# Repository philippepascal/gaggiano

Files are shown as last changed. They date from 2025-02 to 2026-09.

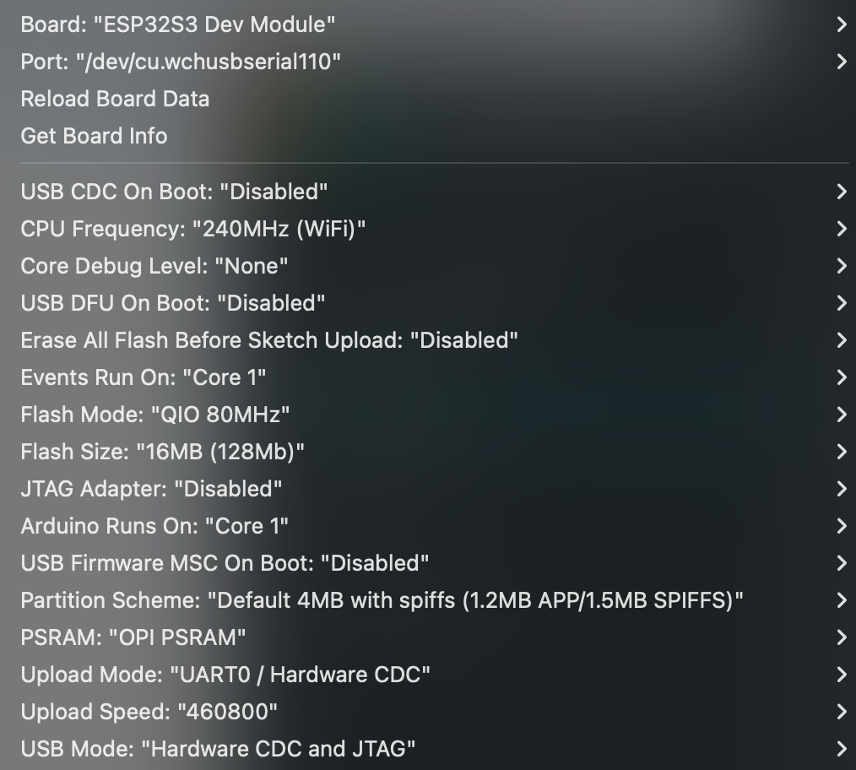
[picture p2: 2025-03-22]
docs/images/arduino-ide-esp32-settings-2025-03.png

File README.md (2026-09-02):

# Gaggiano

Firmware for a Gaggia espresso machine retrofit, inspired by
[Gaggiuino](https://github.com/Zer0-bit/gaggiuino) but written from scratch around two
boards:

| Board | Sketch | Role |
|---|---|---|
| STM32F411CEU6 "Black Pill" | `gaggiano-controller-v1/` | reads boiler temperature (MAX6675) and pressure (ADS1115), drives the boiler SSR, the pump (pulse-skip modulation) and the 3-way solenoid |
| Sunton ESP32-8048S043 (ESP32-S3, 4.3" 800x480 touch) | `gaggiano-v2/` | LVGL touch UI, brew profiles and logs on SD card, sends setpoints to the controller over UART |

The two talk over a 115200 baud serial link with a small text protocol with checksums,
a 1 s heartbeat from the screen and a 3 s safety timeout on the controller; see
`docs/PROTOCOL.md`. The protocol code is shared by both firmwares and tested on the
host (`libraries/GaggiaProtocol/`, `tests/`). Wiring follows the Gaggiuino "Lego build"
schematic in `docs/images/gaggiuino-lego-schematic-v3.9.png` with pin assignments as in
the sketches (`gaggiano-controller-v1/config.h`, `gaggiano-v2/config.h`).

## Building and flashing

Everything goes through the `./gg` script (arduino-cli underneath, no Arduino IDE):

```
./gg setup                 # once: pin the cores, write the local config
./gg build all
./gg flash screen          # esptool over the display's USB port
./gg flash controller      # DFU over USB with dfu-util, no buttons needed after the first flash
./gg monitor controller
./gg test                  # host-side tests of the protocol, profile format, sequencer
```

Both boards answer commands on their USB console (`tools/serial-cmd.py controller STATUS`,
`tools/serial-cmd.py screen STATUS`; `--help` lists them). `docs/BENCH-CHECKLIST.md` is
the manual verification run after a change.

- `docs/BUILD.md`: setup, commands, layout, troubleshooting.
- `docs/FLASH-STM32.md`: how the STM32 gets into DFU, the serial-triggered reboot,
  the button sequence, the ST-Link alternative.
- `sdcard/`: what goes on the display's SD card.
- `docs/2026-09-01-findings.md` and `docs/MIGRATION-PLAN.md`: state of the project and
  the record of the move away from the Arduino IDE.
- `docs/REFACTOR-PLAN.md`: the bug inventory and the refactoring record (protocol v2,
  memory fixes, watchdog, tests).

## Layout

```
gg, tools/            build/flash tooling
gaggiano-controller-v1/, gaggiano-v2/   the two sketches
libraries/            vendored Arduino libraries (with the project lv_conf.h)
sdcard/               SD card content for the display
vendor/               display board datasheets and schematics
gaggiacover/          3D models for the screen enclosure
archive/              first version of the display firmware
docs/                 documentation and images
```

## Known issues and ideas

From `notes.txt`, the working list, updated after the 2026-09 refactor:

- Communication stopping: the screen leaked heap on every status line and ran out
  within minutes; fixed (see `docs/REFACTOR-PLAN.md`, B1). To be confirmed in the machine.
- Pressure readout noisy on the screen: the reader now drains every pending line and
  shows the newest at 5 Hz; smoothing strategy still open.
- Boiler PID does not settle cleanly: zero readings from the MAX6675 used to pass the
  range check and reach the PID; fixed (B2). Re-check in the machine before retuning.
- Steam pressure declines over a long steam; needs a strategy to hold some pressure.
- Full controller logs on the SD card would help tuning; log format needs a header and
  a way to tie settings to a log (hash of the settings).
- Blooming: the pre-infusion fill time may not be consistent between the first and
  subsequent shots; a "stop pump when water detected" command is a candidate fix.

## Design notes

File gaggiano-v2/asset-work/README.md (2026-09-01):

Source images for the UI. Only `logoMainScreen.png` is currently compiled in (as
`../logoMainScreen.c`, generated with the LVGL image converter v8,
https://lvgl.io/tools/imageconverter, RGB565). The others are kept for future use.

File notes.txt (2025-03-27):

sometimes comms stop. no idea what is happening.
complete logs with additional settings or maybe hash of settings to compare with UI
nicer UI?
do I need to stop at detect pressure with special command? blooming fill time might not be consistent if first or subsequent shot

---------------Below is done:

current state:
coffee is decent, pressure control does something, though the readout on the screen is all over the place. need to figure out frequency of updates as controller sends more than screen receives
- let's add the use of Kalman filters to smooth out readings.
- increased greatly loop frequency to allow for many pressure readings.
temperature control seem iffy too. PID doesn't seem to find a way to stabilize at the right temp. often fall to bang bang range before bumping too high.
look into kalman filter

- it would be real nice to see full logs of controller: all messages, with included readings, and outputs over time. would require logging on the screen in the SD card. maybe need to create new log file at every start.
- logging would also probably require to not skip messages if several are logged in. multiple message reading and averaging for display might be good

channelling sometimes, already has a simple way to ease in pressure, not sure if it works great
- steam pressure declines a lot, and PID instability doesn't help. should look at how to maintain a bit of pressure when steaming
- cleaning cycle would be nice to have also, easily lifted from gaggiuino

brew cycle:
1. instanciate pump low until pressure changes (detect water)
    this can't be done in screen...need special function and message
2. if blooming:
2.a. run pump low just enough to add a bit of water
2.b. wait blooming time
3. increase pump smoothly till brew pressure reached
    also needs to be done in controller. but probably ok on all brew cycles
4. run pump on PID until timer done, or button pressed
5. display brew run time for reference to set timer

1.send special prime command: temp + pressure at which to stop pump but not before running a few seconds at desired pressure to add water
2.when pressure read reached desired, controller has already stopped, screen move to blooming
3.if blooming time >0 wait that amount of time
4.resume with simple brewing

- reset logs!!

timer on brew
 - start with display brew time
blooming!

 - add pump settings to advanced settings
 - persist steam settings
 - fix set temp on front panel when steaming
- no header on logs
 - fix sudden drop in pump output. combined with gradual increase, causes massive "holes" in pressure profile

 - fix last brew time random showings

sometimes comms stop. no idea what is happening.
complete logs with additional settings or maybe hash of settings to compare with UI

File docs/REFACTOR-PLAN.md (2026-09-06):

# Refactoring plan: fixes, structure and protocol (started 2026-09-01)

Branch `refactoring`, on top of `main` after the migration. Companion documents:
`docs/2026-09-01-findings.md` (project state), `docs/MIGRATION-PLAN.md` (tooling),
`docs/BUILD.md` and `docs/FLASH-STM32.md` (how to build and flash).

## Scope

In: bug fixes, memory safety, code structure, a robust screen/controller protocol,
host-side tests for the pure logic, bench verification of every step.
Out: new features, UI redesign, core or library upgrades (plan 6.3), anything that
changes what the machine does beyond the documented fixes below.

Rule for every step: it compiles with `./gg build all`, it is flashed with `./gg flash`,
and the bench checklist (R0.3) passes before the next step starts. One commit per
numbered step, message prefixed `refactor:`.

## How to resume after an interruption

1. `git checkout refactoring && git status && git log --oneline -15`.
2. Find the first unchecked box. Steps are ordered inside a phase; phases are ordered.
3. Steps marked **(bench)** need both boards on USB. Nothing here needs the boards in
   the machine until the final soak in R3.
4. Record surprises in the notes log at the end of this file.

## Decisions (answered 2026-09-01)

- D1. Link-loss behaviour on the controller: after N seconds without a valid command,
  pump off and valve closed for sure. Boiler: keep the last temperature setpoint
  (machine stays hot, proposed) or drop to 0? Proposed N = 3 s.
  **Decided: keep the boiler setpoint. N = 3 s.**
- D2. Protocol stays text with a checksum (proposed), not binary. **Decided: yes.**
- D3. Profile names capped at 24 characters (SD filename budget). Longer names are
  truncated on rename. **Default accepted.**
- D4. Enable the STM32 independent watchdog (resets the board if the loop hangs; a
  reset means pump off, valve closed, boiler PWM 0 until the screen re-sends). Proposed yes.
  **Decided: yes, try it.**
- D5. Host tests: plain C++ with a tiny assert helper and a Makefile, run by `./gg test`.
  No framework dependency. Proposed yes. **Default accepted.**
- D6. `double` to `float` on the controller where values only feed float APIs. The
  F411 has a single-precision FPU; doubles are emulated. Proposed: do it only in the
  new code paths (protocol, sensors); leave AutoPID's doubles alone. **Default accepted.**

## Bugs found by reading the code (fixed in the phases below)

| # | Where | What | Effect | Fixed in |
|---|---|---|---|---|
| B1 | both sides, `mySubString` (three copies) | `malloc` per field, never freed | screen leaks ~4 blocks per status line (5/s); controller leaks per command. Likely the "comms sometimes stop" symptom | R1.3 (controller), R2.4 (screen) |
| B2 | controller `readTemperature` | `newReading > 1 \|\| newReading < 200` always true | MAX6675 fault/zero readings pass into the PID | R1.2 |
| B3 | controller `loop` | `LOOP_PERIOD - (millis() - loopStart)` is unsigned; a loop over 10 ms yields a ~49-day `delay()` | firmware freezes with outputs held at their last value | R1.1 |
| B4 | controller `parseMessage` | unknown or truncated message falls through to `operating_mode = BREW` | mode switch on line noise, e.g. during steam | R1.3 |
| B5 | both sides | no checksum, no field-count check | a flipped digit changes a setpoint silently | R2 (checksum, field count) |
| B6 | controller | UART RX buffer 64 bytes, read every 200 ms; longest command 58 bytes | two commands within 200 ms truncate the second | R1.4, R2.4 (512 B on the screen) |
| B7 | screen | commands sent once, never refreshed; controller never times out | a lost "stop" keeps the pump running; a dead link freezes the machine state | R2 (heartbeat, timeout, echo check) |
| B8 | screen `readMessage` | `readStringUntil` blocks up to 50 ms in the UI loop; one line per pass | UI stutter, stale or skipped status lines | R2.4, R3.2 |
| B9 | screen `gaggia_config.cpp` | `malloc(30)` + `strcat` of profile names; `sprintf` of notes into 500 bytes; `new char[500]` never freed | stack/heap overflow with long names or notes; leak per profile load | R3.1 |
| B10 | screen `setupAndReadConfigFile` | reads `values[0..18]` without checking how many rows the CSV had | garbage settings from an old or truncated profile file | R3.1 (profile_format.cpp, tested) |
| B11 | screen `state.notes`, `state.profile_name` | `char*` pointing at leaked heap or string literals | undefined lifetime, leak per load | R3.1 |
| B12 | controller `parseMessage` | 500-byte line buffer on the stack plus `String` from `readStringUntil` | heap churn, stack pressure; no bound on line length | R1.3 |

## Target layout (end state)

```
libraries/GaggiaProtocol/          shared by both sketches and the host tests
  library.properties
  src/gaggia_protocol.h            message types, field lists, limits, version
  src/gaggia_protocol.cpp          encode / decode / checksum, no heap, no Arduino deps
  src/line_reader.h                non-blocking line assembler over any byte source
gaggiano-controller-v1/
  gaggiano-controller-v1.ino       setup() / loop() only
  config.h                         pins, periods, limits
  sensors.{h,cpp}                  MAX6675 + ADS1115 + Kalman
  outputs.{h,cpp}                  boiler PWM, pump (PSM), valve, allOutputsOff()
  control.{h,cpp}                  mode logic (brew / steam / clean), PID glue
  link.{h,cpp}                     screen UART: STAT out, CMD/TUNE in, link timeout
  console.{h,cpp}                  USB serial: VERSION, DFU, STATUS, LOG
  dfu_jump.{h,cpp}                 unchanged
  PSM.{h,cpp}                      unchanged
  build_opt.h                      -DSERIAL_RX_BUFFER_SIZE=256
gaggiano-v2/
  gaggiano-v2.ino                  setup() / loop() only
  display_glue.{h,cpp}             Arduino_GFX panel, LVGL flush, touch (unchanged behaviour)
  sequencer.{h,cpp}                brew/bloom/auto phase machine, pure logic, time injected
  link.{h,cpp}                     controller UART: CMD/TUNE out with heartbeat, STAT in
  storage.{h,cpp}                  SD: profiles, settings, logs (was gaggia_config.cpp)
  gaggia_state.h                   fixed-size strings instead of char*
  lv_buildUI.{h,c}                 UI only; no parsing helpers
tests/
  Makefile                         host build with the system compiler
  test_protocol.cpp, test_sequencer.cpp, test_line_reader.cpp
docs/PROTOCOL.md                   the wire format, one page
```

---

## Phase R0: baseline and safety net (no bench)

- [x] R0.1 Starting commit: `main` at 2f58621 (Migration #1). Save the current
      binaries as `build-baseline/` locally (git-ignored) for size comparison.
- [x] R0.2 `tests/` with a Makefile that compiles listed `.cpp` files with the host
      `c++`, plus `./gg test`. A first trivial test proves the harness. CI runs it.
- [x] R0.3 `docs/BENCH-CHECKLIST.md`: the manual verification run after every flash.
      Draft:
      1. `./gg detect` shows both boards. `./gg monitor controller`, `VERSION` answers.
      2. Screen boots to the main tab; temperature and pressure update about 5 times/s.
      3. Heat on: controller log shows the setpoint; boiler output rises. Heat off.
      4. Brew on for 5 s: valve opens, pump output non-zero, brew timer counts. Brew off:
         valve closes, pump 0.
      5. Steam on/off, clean on/off: mode echoed by the controller.
      6. Settings tab: change a value, Set, reboot the screen, value persists.
      7. Profile tab: duplicate, rename, select, delete. Names survive a reboot.
      8. Leave both boards running 10 minutes; free heap (screen) and loop counter
         (controller) still reported and stable.
      Items 1-2 after every flash; the full list at each checkpoint.
- [x] R0.4 (both verified on bench) Controller console additions needed for the checklist: `STATUS` (mode,
      setpoints, outputs, loop counter, max loop time, link state) and `LOG ON|OFF`
      (silence the per-message debug spam). Screen: print free heap every 10 s to USB.

**Checkpoint R0:** `./gg test` passes, checklist items 1-2 pass with the current
firmware (PASSED 2026-09-01 for the controller; `STATUS` reports maxLoopMs=6 at rest), baseline sizes recorded: controller 68,080 bytes, screen 678,224 bytes.

---

## Phase R1: controller fixes and structure (no protocol change) **(bench)**

The wire format stays exactly as today so the screen keeps working unmodified.

- [x] R1.1 Fix B3: compute elapsed time, `delay` only when elapsed is below the period;
      track the maximum loop time for `STATUS`.
- [x] R1.2 Fix B2 (`&&`), and treat a MAX6675 open-thermocouple reading (NaN or 0) as a
      fault: keep the last good value, count faults, expose in `STATUS`.
- [x] R1.3 Fix B4/B12/B1 on the controller: replace `parseMessage` with a non-blocking
      line assembler (fixed 128-byte buffer, characters pulled every loop pass) and an
      in-place `strtod` field parser. Unknown type or wrong field count: ignore, count.
      Delete `mySubString`, `myIndexOF`, the dead `updatePump`.
- [x] R1.4 Fix B6: `build_opt.h` with `-DSERIAL_RX_BUFFER_SIZE=256`; verify the flag is
      honoured in the verbose build output.
- [x] R1.5 Split the sketch into the files listed above. Pure move, no logic change;
      confirm the `.bin` size is within a few hundred bytes of R1.4.
- [x] R1.6 D4: enable the independent watchdog (STM32duino `IWatchdog`, 4 s), reloaded
      once per loop. Verify: `HANG` console command spins forever; the board resets
      within 4 s and comes back with outputs off.
- [x] R1.7 SKIPPED: the new parser writes into the double setpoints AutoPID points at; converting nothing else buys anything measurable (loop max 6 ms). Revisit if the loop budget gets tight.

**Checkpoint R1:** full bench checklist with the unmodified screen firmware. Ten
minutes of heat + a 30 s brew with the console showing loop max time under 10 ms.
PASSED 2026-09-01. Console items: VERSION, STATUS, LOG, RX injection of valid and
invalid lines, HANG -> watchdog reset in 4 s with wdReset=1, DFU flash with the watchdog
armed. Screen-driven run captured on the controller console with LOG ON: heat on/off
(boiler 100% then 0), brew on/off (valve 1, pump ramp 0.8 -> 126.85 at 0.4/step, then 0),
steam on/off (pump 5.08 = 4% of 127, valve stays 0, boiler 100), clean on/off (valve 1,
pump 255), three advanced-settings sends from Set / duplicate / delete. STATUS after:
rx=12 rxRejected=0 rxOverflows=0 maxLoopMs=6 (with logging on), 575 status lines with
no counter gaps. Not done: the 10-minute heat with water (bench only, no machine).

---

## Phase R2: shared protocol v2 **(bench)**

Both sides change together; both boards are flashed together.

- [x] R2.1 `docs/PROTOCOL.md`. Proposed format (D2), NMEA-style:

      ```
      $TYPE,field,field,...*HH\n
      ```
      `HH` is the XOR of every byte between `$` and `*`, two upper-case hex digits.
      Fields are decimal with at most 2 decimals; a receiver rejects a line whose type
      is unknown, whose checksum fails, or whose field count is wrong. Line length is
      capped at 120 bytes.

      | Type | Direction | Fields | When |
      |---|---|---|---|
      | `HELLO` | both | protocol version, firmware version string | on boot, and as reply to `HELLO` |
      | `STAT` | controller to screen | mode, temp, pressure, valve, boilerOut, pumpOut, tempSet, pressSet, pumpPct, linkOk, faults, counter | every 200 ms |
      | `CMD` | screen to controller | mode (0 off, 1 brew, 2 steam, 3 clean), tempSet, pressSet, pumpPct | on change and every 1 s (heartbeat) |
      | `TUNE` | screen to controller | bbRange, pidCycle, kp, ki, kd, pumpStepUp, pumpKp, pumpKi, pumpKd | on change, and after every controller `HELLO` |

      Controller rules: no valid `CMD` for N s (D1) sets mode 0, pump 0, valve closed,
      `linkOk=0` in `STAT`. Screen rules: if `STAT` echoes a mode or setpoint different
      from what it last sent for more than 1 s, re-send `CMD`. `TUNE` is re-sent whenever
      the controller says `HELLO` (it rebooted). The SD log keeps the raw `STAT` lines;
      the header row changes accordingly.
- [x] R2.2 `libraries/GaggiaProtocol`: encoder, decoder, checksum, `line_reader.h`.
      No heap, no `String`, no Arduino types (a `putc`-style callback for output). Host
      tests: round trip of every message, checksum failure, truncated line, garbage
      before `$`, field count mismatch, oversize line, two lines in one read.
- [x] R2.3 Controller `link.cpp` on the library: `STAT` every 200 ms, `HELLO` at boot,
      `CMD`/`TUNE` handling, link timeout. Mode changes only from a valid `CMD`.
- [x] R2.4 Screen `link.cpp` on the library: heartbeat, echo check, `TUNE` after `HELLO`,
      RX buffer 512 (`setRxBufferSize` before `begin`), all pending lines drained each
      pass, newest `STAT` wins.
- [x] R2.5 (see checkpoint notes) Flash both. Bench: full checklist, then pull the UART wire mid-brew: pump
      stops within N s, `STAT` shows `linkOk=0` on the console; reconnect: screen
      re-sends within 1 s, brew resumes only if still selected on the screen. Reset the
      controller with NRST while heating: screen re-sends `TUNE` and `CMD` unprompted.

**Checkpoint R2:** the above, plus `./gg test` green.
PASSED 2026-09-01 with one item deferred. Host tests: 244 checks green. Bench, screen
console: HELLO exchange at boot, TUNE sent, one rejected partial line at startup as
designed, CMD heartbeat at 1 Hz, every button press one CMD change, zero rejects and
zero re-sends over a 10-minute run, heap flat except during profile/settings saves
(B9, next). Controller reboot with NRST while heating: screen received HELLO, re-sent
TUNE and the heat CMD unprompted. Controller console (by injection): CMD accepted,
mode 0 and linkOk=0 three seconds later. Deferred: the UART wire pull. The screen's
USB bridge dropped at the moment the wire was pulled (twice during hardware handling
in this session, looks like a ground glitch), hiding the re-send message; to be
observed from the controller console at Checkpoint R3 instead.

---

## Phase R3: screen fixes and structure **(bench)**

- [x] R3.1 (bench 2026-09-01: heap flat at 113,112 through two saves, duplicate, three profile switches, delete, notes save; 14 min idle flat) Fix B9/B10/B11: `gaggia_state.h` gets `char profile_name[32]` and
      `char notes[128]`; all filename building through one `snprintf` helper with the D3
      cap; the CSV loader checks the row count and falls back to defaults per missing
      field; every `malloc`/`new` in `storage.cpp` and `lv_buildUI.c` removed or paired
      with a free (target: zero heap allocation after boot outside LVGL and the SD driver).
- [x] R3.2 Fix B8 leftovers: the `i < 20` loop hack becomes time based (`STAT` consumption
      and UI refresh at 5 Hz, `lv_timer_handler` every 5 ms); no blocking reads remain.
- [x] R3.3 `sequencer.cpp`: the bloom/auto/brew phase machine extracted from
      `sendCommand` into a pure function of (state, now) that returns the desired `CMD`.
      Host tests for the phase transitions and timers.
- [x] R3.4 `display_glue.cpp`: panel, LVGL driver, touch and splash moved out of the
      `.ino` unchanged.
- [x] R3.5 Logging: `logController` keeps the file open between lines and flushes once a
      second; `deleteLogsFile` writes the new header. Free-heap line to USB every 10 s.
- [x] R3.6 PARTIAL: parsing helpers removed and fixed-size strings in use (done in R3.1). DEFERRED: folding the ten settings-field blocks (cosmetic, risk of pixel drift) and the delete-selects-first-profile quirk. `lv_buildUI.c`: remove the parsing helpers, use the fixed-size strings, and
      fold the ten copy-pasted settings-field blocks into one helper. Pixel-identical
      screens; (no screenshot of the old UI exists; the file once named so was an IDE capture).
- [x] R3.7 Debug output behind one log-level switch on both sides.

**Checkpoint R3:** full bench checklist, then a 1-hour soak with both boards on USB:
free heap flat on the screen, loop max time stable on the controller, no missed
`STAT` lines in the SD log (counter field contiguous).
PASSED 2026-09-01 (screen on USB, controller powered through the link connector).
Checklist: heat, brew, steam, clean, prime to completion, auto to completion, settings
save, profile duplicate/select/delete: one command change per press, zero rejects, zero
re-sends. Two pre-existing UI bugs found and fixed on the way: the tab bar stayed
disabled after prime/auto ended on their own; the action timer restarted at each phase
(now continuous, and the prime button shows fill+wait). Display precision reduced to the
degree / 0.1 bar / second. Soak 17:16 to 18:16: 360 HEAP lines all at 112,592 bytes;
21,505 status lines received in 4,521 s (4.76/s, matching the 200 ms send period with
loop jitter) with the reject counter unchanged; no port drops. Not done: SD log
continuity (SDLOG left off). UART wire pull done afterwards with the controller on USB:
`link timeout: mode off` 3 s after the unplug, boiler setpoint kept (D1). Pulling the
four-pin link connector also cuts the screen's power in this bench setup, so the replug
is a screen reboot: HELLO exchange, the screen's initial off command applied, heartbeat
resumed. A data-only wire pull is not possible with this connector; the recovery path
via heartbeat and HELLO is demonstrated by the reboot.

---

## Phase R4: wrap-up

- [x] R4.1 README: protocol summary and link to `docs/PROTOCOL.md`; findings doc gets a
      "resolved" column for B1-B12; this plan's boxes ticked.
- [ ] R4.2 One test in the machine: heat, one shot, one steam. Compare against how it
      felt before the refactor; no tuning changes are expected.
- [ ] R4.3 PR `refactoring` to `main`.

## Deferred (not this branch)

- Screen boot blocks for the 5 s splash before the loop and the heartbeat start, so the
  controller sees a 3 s link timeout on every screen reboot (harmless: mode is off
  anyway). A non-blocking splash would remove it.

- Core and library upgrades (migration plan 6.3), 16 MB partition table.
- Items from `notes.txt`: pressure readout smoothing strategy, PID retune, steam
  pressure hold, "stop pump when water detected" prime command, settings hash in logs.
- `double` to `float` inside AutoPID and the PID tuning that would need re-validation.

## Notes log

- 2026-09-01 sensor faults: with the boards idle on the bench, the controller counted
  122 rejected MAX6675 readings in about an hour (one every ~30 s). Before R1.2 these
  zero readings went straight into the boiler PID (the range check was always true),
  which fits the old "PID never settles, drops into bang-bang then overshoots" note.
  Worth re-checking the PID behaviour in the machine before any retuning.

- 2026-09-01 R3.1 bench: after deleting a profile the UI selects the first profile in
  the list (`tigerwalk`), not the one that was selected before the duplicate. Pre-existing
  behaviour in `delete_btn_clicked`; candidate for R3.6.

- 2026-09-01 screen baseline: right after boot the screen reports
  `HEAP free=114128 minfree=105320 psramfree=7590603`.
- 2026-09-01 B1 measured live: with status lines flowing the screen's internal heap
  fell about 4.1 KB per 10 s and reached `free=0` within a few minutes of boot. After
  that, allocations spill into PSRAM at the same ~420 B/s and the UI keeps running, but
  anything needing internal RAM (UART and SD drivers included) is at risk. This is the
  most likely mechanism behind "comms sometimes stop". Fixed in R3.1; the after
  measurement must show a flat HEAP line for 10 minutes.
- 2026-09-01 bench logistics: only one working data cable, so the two boards are put on
  USB one at a time. Either board powers the other over the shared 5 V rail (the display
  board's power connector passes current both ways through Q1), so the UART link stays
  up regardless of which one is on the Mac.

- 2026-09-01 R1: `STATUS` reports maxLoopMs=6 at rest with debug logging off. That is
  close to the 10 ms loop period; with `LOG ON` the USB prints likely pushed some
  iterations past 10 ms, which is exactly the B3 trigger. B3 is fixed, but the
  MAX6675 bit-banged read (every 250 ms) is the main cost and worth a look if the
  budget matters later.
- 2026-09-01 R1.6: the independent watchdog stops on the software reset used for the
  DFU jump (verified: buttonless flash works with it armed), and `wdReset` is reported
  by `STATUS` after a watchdog reset.

- 2026-09-01: plan written from a full read of both sketches, `gaggia_config.cpp`,
  `PSM.cpp` and the UI event handlers. The three `mySubString` copies (controller,
  `gaggia_utils.cpp`, `lv_buildUI.c`) all leak. B3 (unsigned delay underflow) was
  found while planning and is possibly the more direct cause of "comms stop".

- 2026-09-04: field failure, boiler warm, a clean cycle done. 11 s after the clean
  stopped the ADS1115 stopped answering on I2C. Each pressure read then blocked for the
  core's 100 ms I2C timeout (loop counter 10 per second instead of 100) and the library
  returned raw 0, shown as -1.50 bar. The slow loop exposed an unsigned underflow in
  `checkLinkTimeout`: `now` is the loop start while `last_cmd_time` is stamped after the
  read, so every heartbeat was applied then timed out in the same pass (mode off,
  `linkOk=0`, boiler setpoint kept). The screen showed nothing. Fixed: signed difference
  in `checkLinkTimeout`; failed pressure reads keep the last value, count as faults, are
  retried every 250 ms with an I2C bus recovery every 8 failures, and `pressureStale`
  keeps the pump off; `I2C_TIMEOUT_TICK` lowered to 20 ms in `build_opt.h`; the screen
  header warns `CONTROLLER SILENT` / `CONTROLLER IGNORES COMMANDS`. Why the bus hung is
  not known from the log (EMI from the SSR or pump relay on the I2C wires is the
  suspect; check the pull-ups and the routing).
- 2026-09-04 protocol v3: `STAT` carries `pressStale`, `i2cRecoveries` and
  `maxLoopMs`, logged as three more CSV columns, and the screen writes its own event
  rows (`<time>,#,<text>`) into the same session log: commands sent and why, tuning
  sent, controller hello, rejected lines, silent/answering, link warnings, pressure
  sensor stale/live, screen boot. The two firmwares must be flashed together (a v2
  `STAT` is rejected on field count by a v3 screen and the other way round).
- 2026-09-05: pump dead on some boots, fine on others, nothing touched on the
  machine. The `PSM` object (pulse-skip pump driver) is created with `new` and none
  of its counters had an initialiser; the heap is not zeroed at boot, so
  `_stopAfter`/`_counter` came up with whatever the SRAM held. With the wrong
  values the zero-cross ISR takes the "stopAfter reached" branch on the first
  half-cycle and `_skip` stays true for good. The 2026-09-04 build moved the heap
  (new globals) onto cells that happen to power up that way, which is why it
  appeared right after a firmware change. All members now have initialisers;
  `STATUS` prints `zc=` (zero crossings seen) so a missing dimmer signal is
  visible on the bench (checklist row 17).
- 2026-09-05 steam assist, protocol v4: steaming used to run the pump at a fixed
  percent whenever the pressure was under the max, which either did nothing (the
  pump's own pulses raise the line pressure and trip the cut) or overfilled the boiler
  (a 1.4 kW element vaporises about half a gram per second; the pump at 20% delivers
  more, and the excess comes out of the wand as water). Now `steam_assist.cpp` fires
  fixed shots (`steam_shot_s` of pump at the steam pump percent) at least
  `steam_gap_s` apart, only while the pressure is under the max (wand open) and the
  boiler is within 2 degrees of its setpoint (the element has spare heat to flash the
  water). Both timings are per profile, edited in the STEAM group of the settings, and
  travel to the controller in `TUNE` (11 fields). Host test: `tests/test_steam_assist.cpp`.
- 2026-09-05 evening, protocol v5, from the first steam assist log: with the wand open
  the boiler slid from 135 to 127 in 15 s while the heater sat at 20 to 60 percent, the
  10 degree bang-bang band and Kp 5 being too soft for the steam draw; the assist then
  waited at its 2 degree gate. Now steaming with the wand open narrows only the "flat
  out below" side of the bang-bang to `STEAM_OPEN_BB_RANGE` (3 degrees), the PID and the
  off side are unchanged and the wand closed restores the normal band. The gate is an
  absolute `steam_min_temp` per profile ("Assist min °C", 12th `TUNE` field), and the
  AUTO settings group folded into BREW as "Auto brew s" to make room for it.
- 2026-09-06 heater control, protocol v6: the vendored AutoPID library computed its
  derivative divided by the step twice (a million times too small, Kd never acted),
  had no anti-windup (the clamp was commented out) and took the derivative on the
  error. Replaced by `boiler_pid.cpp`, plain C++ with host tests: same bang-bang band
  and P/I arithmetic at today's gains, derivative on the measurement in degrees per
  second, integral clamped to the output range, a step after bang-bang starts from the
  current reading. The morning log also showed a brew pulling the boiler 3 to 4
  degrees under for 25 s with the heater at 28 percent, which is what 1.2 ml/s of
  reservoir water takes: `brewBoostPercent` adds that estimate to the PID output while
  the pump runs in brew mode (pump fraction x `pump_flow_ml_s` x 4.186 x rise / 1400 W,
  cap 40). `pump_flow_ml_s` replaces the unused advanced setting ("Flow ml/s at 100%",
  default 9, 13th `TUNE` field). The AutoPID directory can go.
- 2026-09-06 screen: a log download over WiFi used `streamFile`, which blocks the loop
  for the whole transfer (seconds for a long session): the panel froze and, past 3 s,
  the controller would have timed the link out and stopped a brew. `sendCsvFile` now
  sends 2 KB chunks and services the link and LVGL between them.

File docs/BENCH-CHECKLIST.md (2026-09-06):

# Bench checklist

Run items 1 and 2 after every flash. Run the whole list at each checkpoint of
`docs/REFACTOR-PLAN.md`. "Bench" means both boards on USB and wired to each other over
UART; nothing needs to be in the machine.

Console commands (`tools/serial-cmd.py controller <command>` or `... screen <command>`;
`tools/serial-cmd.py --list` shows ports). Controller: `VERSION`, `STATUS`, `LOG ON|OFF`,
`RX <protocol line>`, `HANG`, `DFU`. Screen: `VERSION`, `STATUS`, `LOG ON|OFF`, `SDLOG ON|OFF`.
With one data cable, put one board on USB at a time; either board powers the other
through the link connector.

| # | Step | Expect |
|---|---|---|
| 1 | `./gg detect` | both boards listed with a port |
| 2 | `VERSION` on the controller | the version string |
| 3 | `STATUS` on the controller | one line with mode, setpoints, readings, outputs, loop counter and max loop time (under 10 ms at rest) |
| 4 | Screen boots | main tab; temperature and pressure labels refresh about 5 times a second |
| 5 | Heat on from the screen | `STATUS` shows the temperature setpoint; boiler output above 0. Heat off: setpoint 0 |
| 6 | Brew on for 5 s | valve 1, pump output above 0, brew timer counting on screen. Brew off: valve 0, pump 0 |
| 7 | Steam on, then off; Clean on, then off | mode echoed in `STATUS` each time |
| 8 | Settings tab: change a value, Set, reboot the screen | value persists |
| 9 | Profile tab: duplicate, rename, select, delete | names correct after a screen reboot |
| 10 | Both boards running 10 minutes | screen prints `HEAP` lines every 10 s with a flat free value; controller loop counter still increasing; `STATUS` max loop time unchanged |
| 11 | Reboot the controller with NRST while the screen is heating | screen console shows `controller hello`, then `TUNE` and the heat `CMD` re-sent |
| 12 | Unplug the UART wire during a brew, wait 5 s, replug | controller console (`LOG ON`): `link timeout: mode off` within 3 s; on replug the next heartbeat restores brew within 1 s |
| 13 | Pull the pressure sensor's I2C wire (SDA or SCL) while heating | `STATUS`: `pressStale=1`, `pressFaults` counting, `i2cRecoveries` counting about every 2 s, `press` frozen at its last value, `linkOk=1`, loop counter still about 100 per second; screen keeps its buttons lit and shows no warning |
| 14 | Replug the I2C wire | within about 2 s `pressStale=0`, `press` live again, counters stop |
| 15 | Clean on with the I2C wire pulled | `STATUS`: mode 3, valve 1, `pumpOut=0.0` (the pump never runs on a stale pressure) |
| 16 | Unplug the UART wire while the screen heats | screen header shows `CONTROLLER SILENT` within 2 s; replug clears it |
| 17 | Power-cycle the machine 5 times (mains off, not just reset) and start a clean on each boot | pressure rises on every boot; `STATUS`: `zc=` climbing by about 100 per second whenever the mains is on |
| 18 | Steam with the wand closed, boiler at its setpoint | `STATUS`: `pumpOut=0.0` throughout (pressure above the max, no shot) |
| 19 | Open the wand while steaming at the setpoint | log: `pump` shows short bursts about `steam_gap_s` apart, none while `temp` is under `steam_min_temp`; `heater` 100 as soon as `temp` is 3 degrees under the setpoint; no water from the wand |
| 20 | Brew at the setpoint with a puck | log: `heater` jumps by about 20 percent the moment `pump` starts and drops back when it stops; `temp` stays within 1.5 degrees of `tempSet` through the shot |

Record anything unexpected in the plan's notes log.

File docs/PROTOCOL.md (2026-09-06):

# Screen / controller protocol, version 6

UART, 115200 8N1, 3.3 V. Controller USART2 (PA2 TX, PA3 RX); screen UART2 (GPIO17 TX,
GPIO18 RX). Text lines, one message per line, implemented once in
`libraries/GaggiaProtocol/` and used by both firmwares and by the host tests.

## Line format

```
$TYPE,field,field,...*HH\n
```

- `$` starts a message; anything before it on the line is ignored (boot noise).
- `TYPE` is one of the words below. Fields are separated by `,`.
- `*HH` is the checksum: XOR of every byte between `$` and `*` (both excluded), as two
  upper-case hex digits. A receiver drops a line whose checksum does not match.
- Numbers are decimal. Floats carry two decimals. Integers have no decimal point.
- A line is at most 120 bytes including `\n`. Longer lines are dropped whole.
- A receiver also drops a line whose type is unknown or whose field count is wrong.
  A dropped line never changes any state; it is only counted.

## Messages

| Type | Direction | Fields | When |
|---|---|---|---|
| `HELLO` | both | `version` (int), `firmware` (string, no commas, max 31 chars) | at boot. The controller also answers a `HELLO` with its own. |
| `STAT` | controller to screen | `mode` `temp` `pressure` `valve` `boilerOut` `pumpOut` `tempSet` `pressSet` `pumpPct` `linkOk` `faults` `counter` `pressStale` `i2cRecoveries` `maxLoopMs` | every 200 ms |
| `CMD` | screen to controller | `mode` `tempSet` `pressSet` `pumpPct` | on change, and every 1000 ms as a heartbeat |
| `TUNE` | screen to controller | `bbRange` `pidCycle` `kp` `ki` `kd` `pumpStepUp` `pumpKp` `pumpKi` `pumpKd` `steamShotS` `steamGapS` `steamMinTemp` `pumpFlow` | on change, and after every controller `HELLO` |

Field meanings:

- `mode`: 0 off (pump off, valve closed, boiler follows `tempSet`), 1 brew (pressure
  control to `pressSet`, valve open while `pressSet` > 0), 2 steam (valve closed, steam
  assist: shots of pump at `pumpPct` for `steamShotS`, at least `steamGapS` apart, only
  while the pressure is below `pressSet`, which means the wand is open, and the boiler is
  at `steamMinTemp` or more; `pumpPct` 0 or `steamShotS` 0 disables. With the wand open
  the heater is also flat out below `tempSet` minus 3 degrees instead of the normal
  bang-bang band), 3 clean (pump full on below `pressSet`, valve open).
- `temp` in degrees C, `pressure` in bar, `valve` 0/1, `boilerOut` 0..100 percent,
  `pumpOut` 0..127 (pulse-skip units), `tempSet` degrees C, `pressSet` bar, `pumpPct`
  percent.
- `steamShotS`, `steamGapS` (v4), `steamMinTemp` (v5) in `TUNE`: steam assist timings in
  seconds and minimum boiler temperature in degrees C, from the profile's steam settings;
  the other `TUNE` fields come from the advanced settings.
- `pumpFlow` (v6, `TUNE`): the pump's flow at full range at brew pressure, ml/s, from the
  advanced settings. While brewing the controller adds a heater feed-forward for the
  incoming water (pump level times this flow times the rise from 20 C to `tempSet`,
  capped at 40 percent) on top of the PID; 0 disables it.
- `linkOk`: 1 while the controller has received a valid `CMD` within the last 3 s.
- `faults`: count of rejected sensor readings since boot (temperature readings out of
  range plus pressure reads that failed on I2C; the controller console `STATUS` splits
  them).
- `counter`: the controller's loop counter (10 ms per count); gaps mean lost lines. A
  counter that climbs slower than 100 per second means the loop is stalling.
- `pressStale` (v3): 1 while the controller has had no valid pressure reading for
  500 ms; the pump is held off in every mode until a reading comes back.
- `i2cRecoveries` (v3): how many times the controller has clocked the I2C bus free
  and re-initialised the pressure ADC since boot.
- `maxLoopMs` (v3): the longest loop pass since the previous `STAT`, in ms. Normally
  under 10.

## Rules

- Controller: if no valid `CMD` arrives for 3 s, it sets mode 0 (pump off, valve closed),
  keeps `tempSet` (the boiler stays hot), and reports `linkOk=0`. The next valid `CMD`
  restores normal operation.
- Screen: it sends the current `CMD` immediately when it changes and at least every
  1000 ms. If two consecutive `STAT` lines echo a mode or setpoint different from the
  last `CMD` sent, it re-sends the `CMD`.
- Screen: it sends `TUNE` when the values change and whenever it receives a `HELLO`
  from the controller (the controller rebooted and has default tuning).
- The screen's SD log stores the `STAT` fields and the screen's own events, see below.

## SD log

One CSV per screen boot under `/gaggia/logs`, downloadable from the web page. The
header row is:

```
time,mode,temp,pressure,valve,heater,pump,tempSet,pressSet,pumpPct,linkOk,faults,counter,pressStale,i2cRecoveries,maxLoopMs
```

- `STAT` rows: one per `STAT` while the controller runs something, one per second
  otherwise. `heater` is `boilerOut`; `pump` is `pumpOut` scaled to percent. `time` is
  `-` until the clock is set.
- Event rows: `<time>,#,<text>`. Written by the screen when a `CMD` is sent for a
  reason other than the heartbeat (`cmd change ...`, `cmd mismatch ...`, `cmd hello
  ...`), when `TUNE` is sent, when a controller `HELLO` arrives (a reboot), when
  lines are rejected (at most one row per second), when the controller goes silent or
  answers again, when it reports the link down while heartbeats are being sent, when
  the pressure reading goes stale or comes back, and at screen boot. The text has no
  commas; readers skip rows whose second field is `#`.

## Example

```
$CMD,1,93.00,9.00,0.00*56
$STAT,1,92.85,8.97,1,34.0,88.40,93.00,9.00,0.00,1,0,123456,0,0,6*..
```

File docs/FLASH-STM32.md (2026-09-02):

# Flashing the STM32 controller

The controller is an STM32F411CEU6 "Black Pill". It is programmed over USB using the
chip's ROM bootloader (DFU). The bootloader lives in ROM, so no firmware bug can brick
the board: the button sequence below always works.

## Three USB identities

| State | VID:PID | What macOS shows | How to see it |
|---|---|---|---|
| Running our firmware | 0483:5740 | `/dev/cu.usbmodem<serial>` | `./gg detect`, `ls /dev/cu.*` |
| DFU bootloader | 0483:df11 | **nothing under /dev** | `./gg detect`, `dfu-util -l` |
| ST-Link probe (optional) | 0483:3748 or 0483:374b | nothing under /dev | `st-info --probe` |

The DFU bootloader is a plain USB device, not a serial port. This is why the Arduino IDE
port menu looked empty even when the board was correctly in DFU mode.

## Normal flash

```
./gg flash controller
```

What happens:

1. The sketch is built into `build/controller/`.
2. If the board is already in DFU mode, go to step 5.
3. If the board is running firmware that understands the `DFU` serial command (see
   below), `gg` sends it and waits up to 5 s for the bootloader to appear.
4. Otherwise it prints the button sequence and polls for the bootloader for 60 s
   (`--timeout` to change).
5. It downloads the binary with `dfu-util` (Homebrew, open source; ST's
   STM32CubeProgrammer is not needed, `--via cubeprog` uses it if installed), retrying
   up to 3 times, then waits for the firmware's serial port to come back.

## The button sequence

On the Black Pill (pinout picture: `gaggiano-controller-v1/Black_pill_pinout.png`):

1. Hold **BOOT0**.
2. Press and release **NRST**.
3. Release **BOOT0**.

Within a second `./gg detect` should list `controller dfu 0483:df11 STM32 BOOTLOADER`.

Known quirks, from experience with this build:

- The solenoid relay can prevent DFU enumeration. Turning brew on from the screen
  before entering DFU has helped.
- Use a direct USB port on the Mac rather than a hub, and a data-capable cable.
  Charge-only cables power the board but the Mac never sees it. The WeAct v2.0
  Black Pill has no CC resistors on its USB-C socket, so a C-to-C cable from a Mac
  may not enumerate at all; use a USB-A to USB-C cable. Label the cable that works.
- macOS occasionally needs a second attempt; `gg` retries automatically.
- After a failed download the bootloader may still be active. Just run
  `./gg flash controller --no-build` again.

## Serial-triggered DFU (no buttons)

The firmware accepts the line `DFU` on its USB serial port (the 9600 baud CDC port,
not the screen link). It zeroes all outputs, stores a marker in an RTC backup register
and resets; on the next boot the marker is detected before anything else runs and
execution jumps to the ROM bootloader. `./gg flash controller` uses this automatically;
`--no-serial-dfu` skips it. Verified on hardware on 2026-09-01.

Manual use: `tools/serial-cmd.py controller DFU` (a bare shell redirect tends to close the
port before the bytes leave the Mac). `tools/serial-cmd.py controller VERSION` prints the
firmware version string; `tools/serial-cmd.py --list` shows the ports; `--help` for more.

## Alternative: ST-Link over SWD

With an ST-Link (or clone) wired to the SWD header (SWDIO, SWCLK, GND, 3V3), the
bootloader is not needed at all:

```
brew install stlink
./gg flash controller --via stlink
```

This also enables debugging with gdb and works even when USB is dead.

## Troubleshooting

| Symptom | Check |
|---|---|
| `No DFU capable USB device available` from dfu-util | board not in DFU; redo the button sequence, check cable/port, relay quirk above |
| DFU seen but download fails at a sector | run again with `--no-build`; if it persists, erase first with `dfu-util -d 0483:df11 -a 0 -s 0x08000000 -D /dev/zero` is not needed; use `--via cubeprog` with STM32CubeProgrammer as a second opinion |
| Board silent after flash | the build must have `usb=CDCgen` (it does, in `tools/targets.sh`); press NRST once |
| `dfu-util not found` | `brew install dfu-util` (`./gg setup` does it) |
| Two `usbmodem` ports | `./gg detect` shows which one is the controller; pass `--port` to `monitor` |

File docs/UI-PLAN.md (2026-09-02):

# UI plan: main screen redesign (started 2026-09-02)

Branch `UIv2`, on top of `main` after the refactor. Companion documents:
`docs/REFACTOR-PLAN.md` (what the code looks like now), `docs/BENCH-CHECKLIST.md`.

## Goals

A main screen that reads at a glance from where you stand at the machine, in a look
that sits next to brushed stainless and a black bezel. Agreed on 2026-09-01/02:

- Header down to 44 px. Profile name on the left (no "profile" label), the notes in
  muted text after it on the same line, a menu icon on the right instead of tabs.
- Readings first: three tiles (boiler temperature, pressure, timer) with a big live
  value and a mini curve of the last 30 s behind it. No setpoint text in the tiles.
- Six buttons in two rows with 12 px gaps that fill the remaining height. Name on one
  line, value on a second, both large.
- One warm accent (amber) for whatever is running, steel blue for steam. Anything
  unavailable while an action runs dims; the layout never jumps.
- Palette: ground `#0F1113`, surface `#171A1D`, steel `#3C434A`, text `#E9ECEF`,
  muted `#8B949E`, amber `#D9A441`, steam `#7FB3D5`.
- Fonts: Montserrat 14 (labels, menu), 20 (button names), 28 (button values),
  48 (tile values). All four are built into lvgl 8.3; 24/26/36 get disabled.

Out of scope on this branch: new behaviour, protocol changes, core upgrades. The
other three views only receive the palette; their layouts are a later pass.

## How to resume after an interruption

1. `git checkout UIv2 && git status && git log --oneline -15`.
2. Find the first unchecked box. Phases are ordered; U1 (the simulator) comes first
   because every later step iterates in it.
3. **(bench)** marks steps that need the screen on USB. Everything else runs on the Mac.
4. One commit per numbered step, message prefixed `ui:`.

## Gotchas to respect throughout

- Rendering: quarter-screen draw buffer, 16-bit color. Flat fills, 1 px borders,
  radii up to 8, no shadows, no gradients (they band).
- Flash: app slot 1,310,720 bytes, currently 679,744 used. The font change is about
  +80 KB. Check the size after U2.
- The UI is C (`lv_buildUI.c`) compiled with the Arduino core; the simulator compiles
  the same file on the Mac, so it must stay free of Arduino types. `millis()` is the
  only Arduino call it makes today.
- All styles live in one file (`theme.c`) so the lvgl 9 port later touches only that
  file and `display_glue.cpp`.
- Every step ends with the UI running in the simulator; bench flashes happen at the
  end of each phase, not each step.

## Target layout (end state)

```
gaggiano-v2/
  theme.{h,c}          palette, fonts, styles by role (tile, button, header, menu)
  history.{h,cpp}      ring buffers of readings for the curves (pure, tested)
  lv_buildUI.c         screens built from theme roles; no colors or sizes inline
sim/
  Makefile             builds lvgl + lv_buildUI.c + theme.c against SDL2 on the Mac
  main.cpp             window, LVGL flush and mouse drivers, fake state driver
  Arduino.h            shim: millis()
  my_logging.cpp       shim: printf
tests/test_history.cpp
```

---

## Phase U1: simulator on the Mac (no bench)

- [x] U1.1 `sim/Makefile`: compiles every `.c` under `libraries/lvgl/src`, plus
      `gaggiano-v2/lv_buildUI.c`, `theme.c`, `history.cpp`, `sequencer.cpp`, and
      `sim/main.cpp`, with `-I libraries` (for `lv_conf.h`), `-I gaggiano-v2`, SDL2
      from `sdl2-config`. Object files under `sim/build/`, git-ignored. `./gg sim`
      builds and runs it.
- [x] U1.2 `sim/main.cpp`: 800x480 SDL window; LVGL display driver whose flush copies
      the draw buffer into an SDL texture; pointer driver from SDL mouse events; a
      fake `GaggiaStateT` and `AdvancedSettingsT`; stub callbacks for the storage
      functions (profiles from a small in-memory list); keys to drive the state:
      `t`/`T` temperature up/down, `p`/`P` pressure, `b` toggles a fake brew, `s`
      steam, `q` quit. The sequencer runs in the loop so bloom/auto behave.
- [x] U1.3 The current UI (before any redesign) runs in the window. Screenshot it
      into `docs/images/ui-before.png` with SDL (key `w` writes a BMP; convert once).

**Checkpoint U1:** `./gg sim` opens the window and the old UI is usable with the mouse.
Status 2026-09-02: headless `--shot` verified (docs/images/ui-before.png); the interactive
window needs a GUI session, to be tried by hand.

---

## Phase U2: theme file and fonts (no bench)

- [x] U2.1 `libraries/lv_conf.h`: enable Montserrat 14, 20, 28, 48; disable 24, 26, 36
      (check nothing else uses them: `grep montserrat gaggiano-v2/`). Default font 14.
- [x] U2.2 `theme.{h,c}`: the palette as `lv_color_t` constants, the four fonts, and one
      `lv_style_t` per role: screen, header, header_title, header_notes, menu_btn,
      tile, tile_value, tile_label, tile_curve, btn, btn_on, btn_on_steam, btn_dis,
      btn_name, btn_value, notes. `theme_init()` builds them; `theme_apply_<role>(obj)`
      helpers. `lv_theme_default_init` stays as the base (dark, with our primary) so
      widgets we do not style explicitly still look consistent.
- [x] U2.3 Apply the theme to the existing screens without changing layouts. Run in the
      simulator. Build for the board and record the flash size.

**Checkpoint U2:** old layout, new palette and fonts, in the simulator; board build
under 800 KB.
PASSED 2026-09-02: docs/images/ui-u2-palette.png; board build 653,312 bytes (was 679,744:
the dropped 24/26/36 fonts weighed more than the new 20/28/48).

---

## Phase U3: main screen (no bench until the end)

- [x] U3.1 `history.{h,cpp}`: `HistoryBuffer` with a fixed capacity (150 points),
      `push(value)`, `count()`, `at(i)`; three buffers (temperature, pressure, timer
      is not curved). Fed from `updateUI` at 5 Hz for pressure and 1 Hz for
      temperature (2-minute window). Host test: wrap-around, ordering, empty state.
- [x] U3.2 Header: 44 px row; profile label (Montserrat 20, text color), notes label
      (14, muted, single line, clipped with an ellipsis, hidden when empty), menu icon
      button on the right (`LV_SYMBOL_LIST`). The tabview keeps the views but its tab
      bar height is 0; the menu is a dropdown with Profiles, Settings, Advanced and
      switches with `lv_tabview_set_act`. On a non-main view the icon shows
      `LV_SYMBOL_LEFT` and returns to Main. Disabling the tabs during an action
      becomes disabling the menu button.
- [x] U3.3 Tiles: three `lv_obj` at 116 px on the surface color, radius 6. Inside each:
      an `lv_chart` (line, no points, no grid, 150 points, shift mode, line 2 px in the
      tile accent, 40 % opacity) filling the tile, a 12 px uppercase label top-left,
      the value (48) with its unit (20, muted) bottom-left. Temperature and pressure
      tiles turn amber (value and curve) while their action runs; the timer tile turns
      amber while a timer runs. Pressure axis fixed 0 to 12 bar, temperature 20 to 160.
- [x] U3.4 Buttons: grid 3 columns x 2 rows, 12 px gaps, stretch to the remaining
      height. Each button: name (20) over value (28). Values: Heat "93 °C", Brew
      "9.0 bar", Prime "7 + 8 s", Steam "135 °C · 4 bar · 4 %" (28 may not fit three
      values; fall back to 20 for that one and check in the simulator), Clean "9 bar",
      Auto "33 s". States: idle (surface, steel border), on (amber fill, dark text;
      steel blue for Steam), disabled (dim text and border).
- [x] U3.5 Notes moved to the header; the bottom panel goes away; the button grid
      takes the space. Timer tile gets "last shot" from `lastBrewTime` when idle (the
      field exists in the state and is unused today; set it when a brew or auto ends).
- [x] U3.6 Simulator pass through every state: idle, heating, brewing, steaming,
      cleaning, prime, auto, and the notes present/absent. Screenshot to
      `docs/images/ui-main.png`.
- [x] U3.7 **(bench)** Flash; bench checklist items 4 to 7; check the curve moves with
      the real pressure reading and that touch targets feel right. Note the `STATUS`
      heap value: the charts and buffers must not move it.

**Checkpoint U3:** the main screen as agreed, on the panel, checklist 4 to 7 passing.

---

## Phase U4: other views, palette only (no bench until the end)

- [x] U4.1 Profiles, Settings, Advanced: apply the theme roles to their existing
      widgets (lists, text areas, keyboard, buttons); fix the one layout that breaks
      with the new fonts if any. The settings tabs keep their layouts.
- [ ] U4.2 (still open, carried to the next branch) The delete-selects-first-profile quirk from the refactor notes: after a
      delete, select the profile that was selected before the deleted one was created
      if it still exists, else the first.
- [x] U4.3 **(bench)** Flash; checklist items 8 and 9.

**Checkpoint U4:** all views in the new palette; settings save and profile operations
unchanged.

---

## Phase U5: wrap-up

- [x] U5.1 `docs/UI.md`: the palette, the roles, how to run the simulator, how to add a
      widget with the theme. README gets the screenshot and a link.
- [x] U5.2 PR `UIv2` to `main`.

## Deferred

- Settings and Advanced view layouts (a form design of their own).
- Non-blocking splash (from the refactor notes).
- Custom font sizes beyond 48 (needs the LVGL font converter; not required now).

## Notes log

- 2026-09-02 merged to main as PR #3 after several simulator/bench rounds: menu instead of
  tabs, tiles with curves, grouped settings, editor overlay, graph view, colors by
  meaning. U5.1 (`docs/UI.md`) folded into the README and the plan; U4.2 stays open.

- 2026-09-02 LVGL memory: adding the graph view's chart series overflowed the 48 KB
  LVGL pool on the board (the assert handler then spins silently: no console output at
  all, the symptom to remember). LVGL now allocates from PSRAM (`LV_MEM_CUSTOM 1`,
  `ps_malloc`; plain `malloc` in the simulator). Static RAM 119 KB -> 33 KB, free heap
  at boot 111 KB -> 152 KB, PSRAM in use by the UI about 80 KB. The draw buffer stays in
  internal RAM. The old `-DLV_MEM_SIZE` override for the simulator is gone.
- 2026-09-02 the controller already reports heater and pump outputs in STAT; the screen
  now keeps them (`boilerOut`, `pumpOut`, `ctrlMode`, `linkOk` in the state) and the
  graph view plots them.

- 2026-09-02 U3: main screen built and rendered in the simulator in the idle and
  brewing scenes (`docs/images/ui-main-idle.png`, `ui-main-brewing.png`). Board build
  752,800 bytes (57 %): the chart widget and the flex/grid layouts cost about 100 KB
  over U2. The simulator got `--scene idle|heating|brewing|steaming` and `--after ms`.
  The perf monitor overlay (FPS/CPU in the corner, on the device too until now) is off.

- 2026-09-02 U1: LVGL's 48 KB pool overflows on the host (64-bit pointers make every
  widget bigger) and the assert handler then spins forever, which looked like a hang.
  `LV_MEM_SIZE` in `lv_conf.h` is now overridable and the simulator passes 512 KB. The
  device keeps 48 KB. `lv_buildUI.c` needed `<stdio.h>`/`<stdlib.h>` (Arduino.h had
  been providing them). The simulator's `--shot` mode uses no SDL at all, so it runs
  from a terminal without a GUI session.

- 2026-09-02: plan written. `docs/images/screen-ui-2025-03-21.png` was an Arduino IDE
  capture, renamed to `arduino-ide-esp32-settings-2025-03.png`; there is no screenshot
  of the old UI, U1.3 makes one from the simulator.

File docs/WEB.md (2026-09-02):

# The screen's web page

Once the screen is on WiFi (Advanced, then WiFi on the panel), open
`http://gaggiano.local` on a phone or computer on the same network. No login. If the
name does not resolve (some Macs are slow with `.local`), use the IP shown on the WiFi
view.

| Path | What |
|---|---|
| `/` | status, three readings, a live chart of the last 150 s (same colors as the panel), download button |
| `/api/status` | JSON, one object: profile, notes, time, temp, pressure, valve, heater %, pump %, tempSet, pressSet, ctrlMode, link, the six button states, phase, timer, lastShot, heap |
| `/api/history` | JSON arrays of the last 300 samples (2 per second): temp, pressure, heater, pump, mode |
| `/logs.csv` | the current session's log as a download |
| `/logs` | JSON list of the session logs on the card, newest first (name, size) |
| `/logs/<name>` | one session log; add `?download=1` for a download |
| `/update` | POST, multipart `firmware` + `password`: flashes the screen and restarts (see BUILD.md) |

The page polls `/api/status` once a second and appends a sample every half second.
Tapping a session in the list draws it in the same chart (downsampled to 300 points);
"Back to live" returns to the running view.

## Log file

One file per session (boot) under `/gaggia/logs/`, named with the date and time once
NTP has set the clock (`20260902-114556.csv`), the last 10 kept. "Clear logs" on the
Settings view starts a new session. One row per status line while the controller runs
something (5 per second), one per second when idle. Columns:

```
time,mode,temp,pressure,valve,heater,pump,tempSet,pressSet,pumpPct,linkOk,faults,counter
```

`time` is local ISO time once NTP has set the clock, `-` before that. `mode` is 0 off,
1 brew, 2 steam, 3 clean. `heater` and `pump` are percent. `counter` is the controller's
loop counter (10 ms per count); gaps mean lost status lines. Open it in a spreadsheet
and plot pressure against time for a shot.

Console: `SDLOG OFF` stops logging for the session.

## Where the page lives

`gaggiano-v2/web/index.html` is the source; `./gg build screen` embeds it into
`gaggiano-v2/web_page.h` (committed) with `tools/embed-web.py`.

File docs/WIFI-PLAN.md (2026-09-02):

# Plan: core upgrade, WiFi, time, web page, OTA (started 2026-09-02)

Branch `advancedStuff`, on top of `main` after the UI redesign. Companion documents:
`docs/UI-PLAN.md` (UI structure, simulator), `docs/BUILD.md`, `docs/BENCH-CHECKLIST.md`.

## Decisions (2026-09-02)

- LVGL stays at 8.3.3. The esp32 core moves to 3.3.11 and Arduino_GFX to its current
  release, which the new core requires. The controller is untouched.
- Features, in priority order: 1. WiFi setup view reached from a button on the Advanced
  view (not from the menu); 2. time via NTP, time zone chosen on the WiFi view; 3. a web
  page with status, a live graph and a log download for spreadsheets, no login; 4. OTA
  firmware update of the screen; 5. optional Bluetooth scale.
- Credentials and time zone live in NVS (the `Preferences` library), not on the SD card.
- The screen is off the bench for now: everything is built and exercised in the simulator
  and the host tests; bench steps are marked **(bench)** and batched for when it is back.

## How to resume after an interruption

1. `git checkout advancedStuff && git status && git log --oneline -15`.
2. Find the first unchecked box. Phases are ordered.
3. One commit per numbered step, message prefixed `wifi:` (or `core:` for W1).

## Gotchas

- Flash: the screen is at 755 KB of a 1.25 MB app slot. WiFi + web server add a few
  hundred KB and OTA needs two slots. W1 switches to the built-in 16 MB partition scheme
  with two 3 MB app slots and a 9 MB FAT data partition (`app3M_fat9M_16MB`). That is a
  full erase of the chip; profiles are on the SD card and survive.
- Core 3.x changes the FQBN option names; `tools/targets.sh` is the only place to edit.
- Arduino_GFX's RGB panel API changed between 1.2.8 and 1.6: `display_glue.cpp` is the
  only file that knows the panel.
- WiFi on the S3 shares internal RAM with everything else. The draw buffer (192 KB) must
  stay in internal RAM; LVGL is already in PSRAM. Check `STATUS` heap after each phase;
  WiFi needs about 40 KB when connected.
- The simulator does not do WiFi: the network module gets a `netStatus()` interface the
  simulator fakes, so the WiFi view and the header clock render on the Mac.
- The web server runs in the loop (the core's synchronous `WebServer`): each request must
  be short. The log download streams the file in chunks; the live page polls a JSON
  endpoint once a second.

## Target layout (end state)

```
gaggiano-v2/
  net.{h,cpp}          WiFi connect/reconnect, NVS credentials, NTP, time zone, status
  webui.{h,cpp}        HTTP server: /, /api/status, /api/history, /logs.csv, mDNS gaggiano.local
  ota.{h,cpp}          ArduinoOTA hooks (5.)
  lv_buildUI.c         WiFi view (button on Advanced), clock in the header
  storage.cpp          log lines with a timestamp once time is known
tools/targets.sh       core 3.3.11 FQBN, 16 MB partition scheme
gg                     flash screen --ota <host>
tests/test_timezones.cpp
docs/WEB.md            what the page shows, the JSON, the CSV columns
```

---

## Phase W1: core upgrade (screen)

- [x] W1.1 `tools/targets.sh`: `ESP32_CORE_VERSION=3.3.11`, FQBN rewritten with the 3.x
      option names, `PartitionScheme=app3M_fat9M_16MB`. `./gg setup` installs the core.
- [x] W1.2 Vendored `libraries/GFX_Library_for_Arduino` replaced by the current release
      (`arduino-cli lib install` into the sketchbook, then committed).
- [x] W1.3 `display_glue.cpp` ported to the new panel classes (`Arduino_ESP32RGBPanel`
      with the timings, `Arduino_RGB_Display`), same pins and timings as today.
- [x] W1.4 Build clean for the board; fix what the new core flags. Record flash and RAM.
      Simulator untouched (LVGL unchanged).
- [x] W1.5 **(bench)** `./gg flash screen` with a full erase once (`EraseFlash=all` for
      that flash only, documented in BUILD.md), then the bench checklist items 1 to 9.
      `STATUS` heap noted as the new baseline.

**Checkpoint W1:** the redesigned UI runs unchanged on core 3.3.11.

---

## Phase W2: WiFi setup view and connection

- [x] W2.1 `net.{h,cpp}`: credentials and time zone in NVS (`Preferences`, namespace
      `gaggiano`); `netBegin()` connects at boot if credentials exist; reconnect with
      backoff; `netStatus()` returns state, SSID, IP, RSSI; `netScan()` lists networks
      (asynchronous, results polled). `netSetCredentials()` saves and reconnects.
- [x] W2.2 WiFi view (tab 6, not in the menu): reached from a "WiFi" button on the
      Advanced view, with the usual back through the profile name. Contents: network
      list from the scan (tap to pick), password field (editor overlay, full keyboard),
      time zone dropdown, Connect / Forget buttons, a status line (connected as ..., IP,
      signal). Rendered in the simulator with a fake status.
- [x] W2.3 Header: a small WiFi symbol next to the menu when connected (dim when not).
- [x] W2.4 `STATUS` console line gains wifi state, IP, RSSI.
- [x] W2.5 **(bench)** join the home network from the panel, power cycle, it reconnects
      by itself. Heap before/after connection recorded.

**Checkpoint W2:** the screen is on the network after a power cycle without touching it.

---

## Phase W3: time

- [x] W3.1 Time zone table: 12 common zones as (name, POSIX TZ string) in
      `timezones.{h,cpp}` (pure, host-tested for the format), default
      America/Los_Angeles; the WiFi view dropdown uses it.
- [x] W3.2 `net.cpp`: `configTzTime()` once connected; `netTimeValid()` when the clock is
      set. Header shows the clock (HH:MM) left of the WiFi symbol when valid.
- [x] W3.3 `storage.cpp`: log lines prefixed with the ISO timestamp when time is valid,
      `-` otherwise; header row updated. "Last shot" keeps seconds; the log carries the
      wall clock.
- [x] W3.4 **(bench)** clock correct on the panel after boot; a log line shows the time.

**Checkpoint W3:** correct local time on the header and in the log.

---

## Phase W4: web page

- [x] W4.1 `webui.{h,cpp}`: `WebServer` on port 80, mDNS `gaggiano.local`. Endpoints:
      `/` (one HTML page, inline CSS/JS, no external assets), `/api/status` (JSON: the
      STATUS fields plus profile and setpoints), `/api/history` (JSON arrays of the
      graph rings), `/logs.csv` (streams the SD log; `Content-Disposition` attachment).
- [x] W4.2 The page: header with profile and state, three big readings, a canvas chart
      fed from `/api/history` at load and `/api/status` every second (same colors as
      the panel), a "Download log" button. Works on a phone. Source kept as a `.html`
      file in `gaggiano-v2/web/` and embedded at build time (a tiny script turns it into
      a C string, run by `./gg build`, committed output).
- [x] W4.3 Log CSV columns documented in `docs/WEB.md`: timestamp, mode, temp, pressure,
      valve, heater, pump, tempSet, pressSet, pumpPct, linkOk, faults, counter. The
      firmware writes that format from W3.3 on (one line per STAT, 5 per second; a
      setting to log at 1 Hz instead if the card fills).
- [x] W4.4 **(bench)** open `http://gaggiano.local` on the phone during a brew; the graph
      follows the panel; the download opens in a spreadsheet. (2026-09-02, by IP)

**Checkpoint W4:** live page and log download from a phone.

---

## Phase W5: over-the-air update

- [x] W5.1 (changed to an HTTP upload, see notes) firmware update with a password from NVS;
      progress shown on the panel; actions stopped and the controller sent an off command
      before the update.
- [x] W5.2 `./gg flash screen --ota [host]`: `curl` upload to `/update` (`gaggiano.local` by
      default), password from `tools/ota-password` (git-ignored).
- [x] W5.3 **(bench)** one OTA update from the Mac with no cable, then a power cycle.
      2026-09-02: 1.47 MB in 24 s by IP, restart, page back with 118 KB heap.

**Checkpoint W5:** the screen updates over WiFi; the USB path still works.

---

## Phase W6: Bluetooth scale (optional)

- [ ] W6.1 Survey which scale (Acaia, Bookoo, Felicita, Decent) and its BLE protocol;
      a `scale.{h,cpp}` with `scaleWeight()`, `scaleTare()`, connection state.
- [ ] W6.2 Weight tile on the main screen when a scale is connected; brew-by-weight as a
      sequencer option (stop at target weight minus a drip offset), host-tested.
- [ ] W6.3 **(bench)** with the actual scale.

## Deferred

- LVGL 9 port. Controller OTA through the screen. Home Assistant / MQTT.
- The delete-selects-first-profile quirk (UI plan U4.2).

## Notes log

- 2026-09-02 after the bench round: session logs are one dated file per boot under
  `/gaggia/logs/` (renamed when the clock arrives, last 10 kept), listed, viewable and
  downloadable from the page; `/api/history` carries `end` and `period`; the panel's
  bounce buffers went to 16 lines against residual pixel flashes under WiFi traffic
  (heap with WiFi up 93 KB); the backlight is switched off during a firmware write,
  where flash programming stalls the panel refresh. Two more OTA updates done this way.

- 2026-09-02 OTA: ArduinoOTA (the espota protocol) authenticated but the device could
  not connect back to the Mac: the screen is on an IoT network (192.168.20.x) and the Mac
  on the main one; connections from the IoT side are blocked, as they should be.
  Replaced by an HTTP upload to the screen's own server (`POST /update`, `Update`
  library), which only needs the Mac-to-screen direction. The web page has the same
  upload form. `.local` resolution from this Mac is slow; the IP works immediately.

- 2026-09-02 bench: erase-flash and first boot on core 3.3.11 fine, UI unchanged, WiFi
  joined from the panel, NTP time, web and OTA announced, reconnect after a power cycle.
  Then two findings: free internal heap with WiFi up was 29 KB (boot 80 KB; the new core
  reserves more for WiFi), and the picture drifted sideways every half second, the known
  ESP32-S3 RGB-panel starvation while WiFi runs. Fix: LVGL draw buffer 120 -> 48 lines
  (frees ~115 KB internal) and 8-line bounce buffers on the panel (`bounce_buffer_size_px`
  in Arduino_GFX). Heap with WiFi up: 115 KB.

- 2026-09-02 W4/W5 built, bench pending: `webui.cpp` (WebServer, `/`, `/api/status`,
  `/api/history` streamed, `/logs.csv`, mDNS once connected), the page in
  `gaggiano-v2/web/index.html` embedded by `tools/embed-web.py` from `./gg build`,
  CSV log rows (every line while running, 1/s idle; logging on by default), `ota.cpp`
  (ArduinoOTA, progress notice on the panel, actions stopped first), `./gg flash screen
  --ota [host]` through the core's `espota.py`. Firmware 1,488,659 bytes (47 %), static
  RAM 67 KB.

  Bench list for when the screen is back: W1.5 (`./gg flash screen --erase`, checklist
  1-9, heap baseline), W2.5 (join the network, power cycle), W3.4 (clock, log line),
  W4.4 (page on the phone during a brew, CSV in a spreadsheet), W5.3 (one OTA update).

- 2026-09-02 W2/W3 built and rendered in the simulator (`--scene wifi`, `wifi-off`),
  bench pending: `net.cpp` (WiFi STA with reconnect, credentials and zone in NVS, SNTP
  via `configTzTime`), `timezones.cpp` (12 zones, tested), WiFi view reached from the
  Advanced view, header clock and WiFi symbol, `STATUS` fields, timestamped log lines.
  Firmware 1,386,571 bytes (44 % of the 3 MB slot): the WiFi stack adds ~600 KB, which
  is why the partition change came first. Static RAM 62 KB.

- 2026-09-02: plan written; core 3.3.11 installed into `.arduino-data` (2.0.17 kept
  alongside for a rollback). Arduino_GFX 1.2.8 -> 1.6.7. The screen built on the new
  core at the first attempt: 790,416 bytes (25 % of the 3 MB slot), static RAM 37,856.
  `./gg flash screen --erase` added for the one-time partition change.

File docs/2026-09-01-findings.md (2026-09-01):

# Gaggiano: state of the project and tooling (findings, 2026-09-01)

Snapshot taken before the migration away from the Arduino IDE. Everything below was
verified on this Mac (Darwin 25.6, Apple Silicon) on 2026-09-01. Paths are absolute so
the document stays useful from any working directory.

## 1. Repositories and folders

| What | Where | Notes |
|---|---|---|
| Project repo | `~/repos/Gaggiano` | remote `github.com/philippepascal/gaggiano`, branch `migration` for this work |
| Upstream Gaggiuino clone | `~/repos/gaggiuino` | Zer0-bit main branch, README only. Not our code. |
| Old sketchbook path | `~/repos/Arduino` | **No longer exists.** It was renamed to `Gaggiano`. |
| Arduino IDE config | `~/.arduinoIDE/arduino-cli.yaml` | `directories.user` still points at `~/repos/Arduino` (dead) |
| Arduino data dir | `~/Library/Arduino15` | cores, tools, package indexes. Shared by IDE and `arduino-cli`. Since the isolation step, `gg` uses `.arduino-data/` inside the repo instead. |

The dead sketchbook path is the most likely single cause of the IDE feeling flaky: the IDE
cannot find `libraries/`, recent-sketch entries are broken, and the board/port memory is
per-workspace so it resets.

## 2. The two firmware targets

### 2.1 STM32 controller (`gaggiano-controller-v1/`)

- Hardware: STM32F411CEU6 "Black Pill". Reads MAX6675 thermocouple (bit-banged SPI on
  PA5/PA6/PB4), ADS1115 pressure sensor over I2C (PB6/PB7), drives boiler SSR on PB5 via
  hardware timer PWM (30 Hz), pump via PSM zero-cross dimming (PA15 sense, PB3 control),
  solenoid on PC13. Talks to the screen on USART2 (PA2 TX / PA3 RX) at 115200.
- Debug output on USB CDC `Serial` at 9600.
- Files: `gaggiano-controller-v1.ino`, `PSM.cpp/.h` (copied from banoz/PSM.Library).
- Libraries used: AutoPID, SimpleKalmanFilter, ADS1X15, MAX6675, Wire.
- Arduino core: **STMicroelectronics:stm32 2.9.0** (installed; the index now lists 2.11.0, we stay pinned).
- Exact FQBN (from the archived `build.options.json`, matches the screenshot in the folder):

  ```
  STMicroelectronics:stm32:GenF4:pnum=GENERIC_F411CEUX,xserial=generic,usb=CDCgen,xusb=FS,opt=osstd,dbg=none,rtlib=nanofp,upload_method=dfuMethod
  ```
  Extra build property used by the IDE: `build.warn_data_percentage=75`.
- Archived build (2025-03-28): `.bin` 67,140 bytes, `.hex` 188,906 bytes. Source has
  changed since (last edit 2025-09-28) so expect a nearby but not identical size.

### 2.2 ESP32-S3 display (`gaggiano-v2/`)

- Hardware: Sunton ESP32-8048S043, 4.3" 800x480 RGB panel (ST7262), GT911 capacitive touch
  on I2C (SDA 19 / SCL 20 / RST 38), SD card on SPI (SCK 12 / MISO 13 / MOSI 11 / CS 10),
  USB-to-serial via CH340 (VID 0x1a86 PID 0x7523). 16 MB flash, 8 MB OPI PSRAM.
- Talks to the controller on UART2, RX GPIO 18 / TX GPIO 17, 115200. Debug on `Serial` 115200.
- SD card layout used by the firmware: `/gaggia/gaggia_settings.csv`, `/gaggia/profiles/`,
  `/gaggia/selectedProfile`, `/gaggia/gaggia_logs.csv`, `/gaggia/frank.bmp` (+ generated
  `frank_opt.bin`). The card is FAT.
- Files: `gaggiano-v2.ino`, `lv_buildUI.c/.h` (LVGL UI), `gaggia_config.cpp/.h` (SD,
  profiles, logs), `gaggia_state.h`, `gaggia_utils.*`, `touch.h`, `BmpClass*.h`,
  `my_logging.*`, plus LVGL image arrays (`*.c`).
- Libraries used: lvgl 8.3.3 with project `libraries/lv_conf.h` (16-bit color, no swap,
  custom tick, perf monitor on), Arduino_GFX ("GFX Library for Arduino") 1.2.8, TAMC_GT911,
  SD, FS, SPI, Wire, CSV_Parser. `touch.h` includes FT6X36/XPT2046 headers only inside
  `#ifdef` blocks that are off, so those libraries are not needed.
- Arduino core: **esp32:esp32 2.0.17** (installed). Latest is 3.3.2. Upgrading is a real
  port (Arduino_GFX API changed, lvgl 8 to 9), out of scope for this migration.
- Exact FQBN (archived `build.options.json`, matches the screenshot `esp32-arduino.png`):

  ```
  esp32:esp32:esp32s3:UploadSpeed=460800,USBMode=hwcdc,CDCOnBoot=default,MSCOnBoot=default,DFUOnBoot=default,UploadMode=default,CPUFreq=240,FlashMode=qio,FlashSize=16M,PartitionScheme=default,DebugLevel=none,PSRAM=opi,LoopCore=1,EventsCore=1,EraseFlash=none,JTAGAdapter=default
  ```
  Every option value above exists in the installed `boards.txt` (`UploadSpeed=460800` is
  defined for macOS and Linux only).
- Partition scheme is "default" (4 MB layout: app0/app1 1.25 MB each, 1.4 MB SPIFFS) even
  though the chip has 16 MB. A `partitions.csv` identical to the default is in
  `archiveArdIDEFiles/`. App size limit is 1,310,720 bytes; the archived build was
  1,048,672 bytes (80%). Something to watch as the UI grows.
- Archived build (2025-03-28): `.bin` 1,048,672, `.bootloader.bin` 15,104,
  `.partitions.bin` 3,072.

### 2.3 Screen-to-controller protocol (for reference)

ASCII lines, fields separated by `;`, terminated by `|` then newline. First field is the
message type: `0` status from controller (temp, pressure, solenoid, boiler out, pump out,
setpoint, PID params, loop counter), `1` brew (temp;pressure), `2` steam
(temp;maxPressure;pumpPercent), `3` clean (temp;pressure), `9` advanced settings (10 floats).

## 3. Toolchain present on this Mac

| Tool | Version | Location | Used for |
|---|---|---|---|
| Arduino IDE | 2.3.5 | `/Applications/Arduino IDE.app` | current (flaky) workflow |
| arduino-cli | 1.3.1 (Homebrew) | `/opt/homebrew/bin/arduino-cli` | new workflow. Already sees the same cores because it defaults to `~/Library/Arduino15`. Its own config is empty (no STM32 board URL, sketchbook defaults to `~/Documents/Arduino` which is empty). |
| STM32 core | 2.9.0 | `~/Library/Arduino15/packages/STMicroelectronics/hardware/stm32/2.9.0` | with xpack-arm-none-eabi-gcc 13.2.1, STM32Tools 2.2.4, xpack-openocd 0.12.0-4 |
| esp32 core | 2.0.17 | `~/Library/Arduino15/packages/esp32/hardware/esp32/2.0.17` | with xtensa-esp32s3-elf-gcc 8.4.0 (esp-2021r2-patch5), esptool 4.5.1 binary |
| STM32CubeProgrammer | 2.18.0 (the app's Info.plist says 2.4.0; the CLI banner says 2.18.0) | `/Applications/STMicroelectronics/STM32Cube/STM32CubeProgrammer/STM32CubeProgrammer.app/Contents/MacOs/bin/STM32_Programmer_CLI` | the STM32 core's DFU upload calls this. A second copy ships inside STM32CubeIDE. |
| stlink (st-flash, st-info) | 1.8.0 (Homebrew) | `/opt/homebrew/bin` | optional SWD flashing if an ST-Link is used later |
| dfu-util | 0.11 (Homebrew) | `/opt/homebrew/bin` | can list DFU devices (`dfu-util -l`); not what the core uses to flash |
| python3 | 3.14 (Homebrew), also 3.11/3.13 | `/opt/homebrew/bin/python3` | helper scripts; `convertBmp.py` needs Pillow |
| Editors | VS Code, Zed, Sublime | `/Applications` | no PlatformIO installed |
| gnu-getopt | not installed | | the core's `stm32CubeProg.sh` warns and falls back to short options; harmless |

How the IDE actually uploads today:

- STM32: `stm32CubeProg.sh -i dfu -f <sketch>.bin -o 0x0 -v 0x0483 -p 0xdf11`, which runs
  `STM32_Programmer_CLI --connect port=usb1 VID=0x0483 PID=0xdf11 --quietMode --download <bin> 0x8000000 --start 0x8000000`.
- ESP32: `esptool --chip esp32s3 --port <cu.usbserial-XXXX> --baud 460800 --before default_reset --after hard_reset write_flash -z --flash_mode qio --flash_freq 80m --flash_size 16MB 0x0 bootloader.bin 0x8000 partitions.bin 0xe000 boot_app0.bin 0x10000 sketch.bin`.

## 4. USB identities (why the STM32 is "not detected")

| Device state | VID:PID | Shows up as | Notes |
|---|---|---|---|
| STM32 running our firmware | 0483:5740 | `/dev/cu.usbmodem<serial>` (CDC) | this is the port seen in the IDE screenshot |
| STM32 in DFU (system bootloader) | 0483:df11 | **no `/dev/cu.*` entry** | raw USB device; only visible via `dfu-util -l`, `STM32_Programmer_CLI -l usb`, or `system_profiler SPUSBDataType` |
| STM32 in DFU, seen by IDE | | "STM32 BOOTLOADER" via dfu-discovery | the IDE's DFU discovery is what usually fails to refresh |
| ESP32 board (CH340) | 1a86:7523 | `/dev/cu.usbserial-XXXX` or `/dev/cu.wchusbserial*` | esptool auto-resets; no buttons |
| ESP32-S3 native USB | 303a:1001 | `/dev/cu.usbmodem*` | not used: `CDCOnBoot=default` (off) and `USBMode=hwcdc` |

All five VID:PIDs above (plus one unknown 1963:0072) appear in the IDE's board-lookup cache
(`~/Library/Arduino15/inventory.yaml`), confirming these are the devices that were plugged in.

Entering DFU on the Black Pill: hold BOOT0, press and release NRST, release BOOT0. The
bootloader is in ROM and cannot be bricked by firmware. Two quirks recorded in the sketch's
own comments: (a) the solenoid relay interferes with DFU enumeration, and turning brew on
first helps; (b) USB CDC must be enabled in the build for `Serial` to exist at all.

## 5. Repository contents worth cleaning

Sizes are on-disk; the repo's `.git` is 141 MB.

| Item | Size / count | Verdict |
|---|---|---|
| `4-2.3inch_ESP32-8048S043/` (Sunton vendor pack: demos, docs, Windows flash tool) | 294 MB, 2155 tracked files | keep only spec, schematic, user manual under `vendor/`; drop the rest from the tree (history keeps it) |
| `libraries/` (vendored Arduino libraries + `lv_conf.h`) | 158 MB on disk, 1830 tracked files | **keep**; this is what makes builds reproducible |
| `gaggiano-v2/bin`, `lib`, `include`, `pyvenv.cfg` | Python venv created inside the sketch | delete; `pyvenv.cfg` is tracked, `.gitignore` misspells it as `pyenv.cfg` |
| `gaggiano-v2/*.c` LVGL image arrays | 8 files, ~4.5 MB of source | only `logoMainScreen.c` is referenced (`LV_IMG_DECLARE`). `boiler*.c`, `brew*.c`, `steam*.c`, `img_clothes.c`, `img_demo_widgets_avatar.c`, `img_lvgl_logo.c` appear unused and are compiled on every build (linker drops them, compile time does not) |
| `gaggiano-v2/archiveArdIDEFiles/` | 8 MB `compile_commands.json`, 16 MB `.elf`, 15 MB `.map` | keep `build.options.json`, `partitions.csv`, `notes`; delete the rest once the CLI build is verified |
| `gaggiano-controller-v1/archiveArdIDEFiles/` | 1 MB `compile_commands.json`, `.map`, `.elf` | same treatment |
| `gaggiano-v2/frank.bmp`, `frank.jpg`, `frank.rgb565`, `Screenshot*.png`, `ESP32-8048S043-macsbug.pdf` | ~6 MB | move SD-card content to `sdcard/`, docs to `docs/`, drop duplicates |
| `SD_Test/`, `play_lcd/`, `p11_CrystalBall_scroll/` | scratch sketches | delete or move to `scratch/` |
| `gaggiano-v1/` | first version, single `.ino` | move to `archive/` |
| `.DS_Store` files | tracked at root and in `libraries/` | untrack; `.gitignore` already lists it |
| `stm32-comp-build.png` (upstream Gaggiuino schematic), `esp32-arduino.png` (IDE settings screenshot) | root | move to `docs/images/` |
| `gaggiacover/` | 3D models | keep as is |
| `notes.txt` | working notes / todo | keep; fold into docs later |

## 6. Decisions taken on 2026-09-01

- Target repo is `~/repos/Gaggiano`, work happens on branch `migration`.
- Build system: `arduino-cli` driven by a repo script, not PlatformIO.
- Cores stay pinned at STM32 2.9.0 and esp32 2.0.17. No library upgrades.
- ST-Link/SWD stays an optional path (no soldering for now); DFU remains the default.
- A small firmware change to enter DFU from a serial command is approved, provided the
  BOOT0/NRST button sequence keeps working as the fallback (it does: the bootloader is in ROM).
- Repository cleanup is in scope, as a separate phase after the build is proven.

See `docs/MIGRATION-PLAN.md` for the step-by-step plan.

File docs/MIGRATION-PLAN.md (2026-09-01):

# Migration plan: Arduino IDE to a scripted arduino-cli workflow

Companion to `docs/2026-09-01-findings.md` (read that first for the "why").
Work happens on branch `migration` in `~/repos/Gaggiano`.

## How to resume after an interruption

1. `git checkout migration && git status && git log --oneline -15` to see what landed.
2. Find the first unchecked box below. Steps are ordered; each phase ends with a
   checkpoint that must pass before moving on.
3. Anything marked **(hardware)** needs the board plugged in and a human at the machine.
4. Commit at the end of every numbered step with a message starting `migration:`.
   Keep commits small so a half-done phase is easy to bisect or revert.

Conventions: `$REPO` = `~/repos/Gaggiano`. `$A15` = `~/Library/Arduino15`.
`gg` = the repo entry-point script introduced in Phase 2.

## Target layout (end state)

```
Gaggiano/
  gg                         # bash entry point: setup | build | detect | flash | monitor | clean
  tools/
    arduino-cli.yaml         # repo-local arduino-cli config (sketchbook = repo, data = $A15)
    targets.sh               # one FQBN + ports + baud per target, sourced by gg
    usb-detect.py            # VID:PID classification helper (python3, stdlib only)
    convertBmp.py            # moved from gaggiano-v2/
  gaggiano-controller-v1/    # unchanged sketch + sketch.yaml (optional, see 2.5)
  gaggiano-v2/               # unchanged sketch + sketch.yaml (optional)
  libraries/                 # vendored libraries, unchanged
  build/                     # gitignored, exported binaries per target
  docs/
    2026-09-01-findings.md
    MIGRATION-PLAN.md
    BUILD.md                 # setup, build, flash, monitor from a fresh clone
    FLASH-STM32.md           # DFU dance, serial-triggered DFU, relay quirk, ST-Link option
    images/
  sdcard/gaggia/             # what goes on the display's SD card
  vendor/sunton-esp32-8048s043/   # spec, schematic, user manual only
  archive/gaggiano-v1/
  .github/workflows/build.yml     # compile both targets on push
```

---

## Phase 0: Preparation (no hardware)

- [x] 0.1 Write `docs/2026-09-01-findings.md` and this plan.
- [x] 0.2 Add `build/` and `.arduino-cli/` (if used) to `.gitignore`. Commit.
- [x] 0.3 Create `tools/arduino-cli.yaml`:
      ```yaml
      board_manager:
        additional_urls:
          - https://github.com/stm32duino/BoardManagerFiles/raw/main/package_stmicroelectronics_index.json
      directories:
        data: /Users/philippepascal/Library/Arduino15   # reuse installed cores
        user: /Users/philippepascal/repos/Gaggiano       # so libraries/ is the sketchbook libs
        downloads: /Users/philippepascal/Library/Arduino15/staging
      sketch:
        always_export_binaries: true
      ```
      Note: `directories.user` must be absolute; `gg setup` should regenerate this file
      from the repo path so it works on another machine (template + sed, or pass
      `--config-dir`). Decide during 2.1; for Phase 1 hard-coding is fine.
      Verify with `arduino-cli --config-file tools/arduino-cli.yaml core list` showing
      `STMicroelectronics:stm32 2.9.0` and `esp32:esp32 2.0.17`.
- [x] 0.4 MOOT (see notes log, isolation). Optional, ask first: point the IDE's `~/.arduinoIDE/arduino-cli.yaml`
      `directories.user` at `~/repos/Gaggiano` so the IDE keeps working as a fallback.

**Checkpoint 0:** `arduino-cli --config-file tools/arduino-cli.yaml lib list` shows the
vendored libraries (lvgl 8.3.3, GFX Library for Arduino 1.2.8, ADS1X15 0.5.2, ...).

---

## Phase 1: Reproduce both builds from the command line (no hardware)

- [x] 1.1 Compile the controller:
      ```
      arduino-cli --config-file tools/arduino-cli.yaml compile \
        --fqbn "STMicroelectronics:stm32:GenF4:pnum=GENERIC_F411CEUX,xserial=generic,usb=CDCgen,xusb=FS,opt=osstd,dbg=none,rtlib=nanofp,upload_method=dfuMethod" \
        --build-property build.warn_data_percentage=75 \
        --output-dir build/controller --warnings default \
        gaggiano-controller-v1
      ```
      Expect `build/controller/gaggiano-controller-v1.ino.bin` around 67 KB and a flash
      usage line similar to the IDE's. Record the size in this file.
- [x] 1.2 Compile the display:
      ```
      arduino-cli --config-file tools/arduino-cli.yaml compile \
        --fqbn "esp32:esp32:esp32s3:UploadSpeed=460800,USBMode=hwcdc,CDCOnBoot=default,MSCOnBoot=default,DFUOnBoot=default,UploadMode=default,CPUFreq=240,FlashMode=qio,FlashSize=16M,PartitionScheme=default,DebugLevel=none,PSRAM=opi,LoopCore=1,EventsCore=1,EraseFlash=none,JTAGAdapter=default" \
        --build-property build.warn_data_percentage=75 \
        --output-dir build/screen --warnings default \
        gaggiano-v2
      ```
      Expect `.bin` (about 1.05 MB), `.bootloader.bin`, `.partitions.bin`. Record sizes.
      If the build picks up the venv or vendor folders as sources, that is the signal to
      pull Phase 6.1 forward (delete the venv) before continuing.
- [x] 1.3 Compare against the archived IDE builds in `*/archiveArdIDEFiles/` (size, and
      `arm-none-eabi-size` / `xtensa-esp32s3-elf-size` on the `.elf`). Differences must be
      explainable by the source edits since 2025-03-28, not by different flags. Diff the
      compiler command line against the archived `compile_commands.json` first entry if in doubt.

**Checkpoint 1:** both targets compile with zero new warnings and produce binaries. Sizes
recorded here:

| Target | .bin bytes (CLI) | .bin bytes (IDE 2025-03-28) |
|---|---|---|
| controller | 67,492 (text 66,392 vs 66,048) | 67,140 |
| screen | 678,208 (text 466,037 vs 466,665; data 212,056 vs 581,904) | 1,048,672 |

Verified 2026-09-01: the compiler flag sets for the sketch translation unit are identical
between the archived IDE build and the CLI build for both targets (207 and 30 include
paths respectively, same defines). The 370 KB drop in the screen binary is const data:
the March 2025 UI embedded six status icons (`boiler`, `brew`, `steam` and their `Red`
variants) that the current UI no longer references. Their `.c` files are still in the
sketch and are removed in Phase 5.2.

---

## Phase 2: Repo-owned build script and docs (no hardware)

- [x] 2.1 `tools/targets.sh`: one block per target with `FQBN`, `SKETCH_DIR`, `OUT_DIR`,
      `MONITOR_BAUD` (controller 9600, screen 115200), `USB_RUN_VIDPID`, `USB_DFU_VIDPID`
      (controller only: run `0483:5740`, DFU `0483:df11`; screen `1a86:7523`).
- [x] 2.2 `gg` script, bash, `set -euo pipefail`, subcommands:
      - `setup`: check/install Homebrew `arduino-cli`; write `tools/arduino-cli.yaml` from
        the repo path; `core update-index`; `core install STMicroelectronics:stm32@2.9.0`
        and `esp32:esp32@2.0.17` if missing; check STM32CubeProgrammer CLI exists at the
        known path or on `PATH`; print a summary table.
      - `build <controller|screen|all>`: the Phase 1 commands, output to `build/<target>/`.
      - `clean`: remove `build/` and the arduino-cli sketch cache for these sketches.
      - `monitor <target> [port]`: `arduino-cli monitor -p <port> -c baudrate=<baud>`,
        port auto-picked via `detect`.
      - `detect`, `flash`: Phase 3.
      - `--help` on every subcommand; errors are one clear line, not a stack of shell noise.
- [x] 2.3 `docs/BUILD.md`: fresh-clone setup, the three commands (`setup`, `build`,
      `flash`), where binaries land, how to change an FQBN option, how to add a library.
- [x] 2.4 GitHub Actions `.github/workflows/build.yml`: ubuntu runner, install
      arduino-cli, install the two pinned cores, `./gg build all`. Upload binaries as
      artifacts. (Compile only; no upload step.)
- [x] 2.5 SKIPPED. `sketch.yaml` build profiles in each sketch folder pinning the core
      version, so `arduino-cli compile --profile default` works without `gg`. Only worth it
      were skipped on 2026-09-01: profile builds install the platforms again into an
      isolated directory (another ~1 GB download for the esp32 core) and `--dump-profile`
      lists libraries by Library Manager name, which would bypass the vendored copies.
      `gg` already pins cores and options; revisit only if profiles become useful for CI.

**Checkpoint 2:** on a fresh clone in a temp dir, `./gg setup && ./gg build all` succeeds
and produces the same binaries as Phase 1. CI is green.

Result 2026-09-01: passed locally. Controller binary byte-identical from the fresh clone.
Screen binary differs by 3.6 KB only because LVGL logging embeds `__FILE__` absolute
paths (46 path strings, longer in the temp clone). CI not yet observed: the branch has
not been pushed. Check the Actions tab after the first push.

---

## Phase 3: Detection and flashing helpers **(hardware)**

- [x] 3.1 (code written, tested only against a USB hub) `tools/usb-detect.py`: runs `system_profiler SPUSBDataType -json` and
      `arduino-cli board list --format json`, joins on VID:PID, prints one line per known
      device: `controller RUN  /dev/cu.usbmodemXXXX`, `controller DFU  (no port)`,
      `screen /dev/cu.usbserial-XXXX`, plus unknown devices. Exit code 0 if at least one
      known device. Also used by `gg detect`. Fallback for DFU visibility: `dfu-util -l`.
- [x] 3.2 (hardware-tested 2026-09-01: first attempt hit the macOS CH340 'Device not configured' error, retry succeeded at 460800; retry/fallback added to `gg`) `gg flash screen`: `gg build screen`, pick the CH340 port (error with the
      list of candidates if there are several, `--port` override), then run esptool with
      the exact argument list from the findings doc (bootloader 0x0, partitions 0x8000,
      `boot_app0.bin` 0xe000 from `$A15/packages/esp32/hardware/esp32/2.0.17/tools/partitions/`,
      app 0x10000). Prefer `arduino-cli upload` if it reproduces the same command; else
      call esptool directly. Test on the board.
- [x] 3.3 (hardware-tested 2026-09-01 with the button sequence, then buttonless) `gg flash controller` via DFU, in this order:
      1. `gg build controller`.
      2. If a controller in RUN mode is present and firmware supports it (Phase 4), send
         the reboot-to-DFU command on its CDC port.
      3. Poll for `0483:df11` every 0.5 s for up to 30 s. While waiting, print once:
         "Hold BOOT0, tap NRST, release BOOT0" and the relay note from the findings doc.
      4. Flash: `STM32_Programmer_CLI --connect port=usb1 VID=0x0483 PID=0xdf11 --quietMode --download build/controller/<name>.bin 0x8000000 --start 0x8000000`.
         Retry up to 3 times on connect failure (macOS sometimes needs a second attempt).
      5. Wait up to 10 s for `0483:5740` to reappear and report "controller is back".
      Options: `--no-build`, `--timeout N`, `--erase`.
- [x] 3.4 (code written, untested: no probe) `gg flash controller --via stlink` (optional path): `st-flash --reset write
      build/controller/<name>.bin 0x8000000`. Only wire this when an ST-Link is actually
      connected to SWD; document it in `docs/FLASH-STM32.md` as the no-buttons alternative.
- [x] 3.5 `docs/FLASH-STM32.md`: USB identity table, the button sequence with a photo or
      pin diagram (`Black_pill_pinout.png` already in the repo), the relay quirk,
      troubleshooting list (no DFU device: try another cable/port, no hub; DFU seen but
      download fails: retry, or `--erase`; board silent after flash: check `usb=CDCgen`).

**Checkpoint 3:** one successful `gg flash screen` and one `gg flash controller` with the
button sequence, followed by `gg monitor controller` showing "serial works".
PASSED 2026-09-01.

---

## Phase 4: Serial-triggered DFU in the controller firmware **(hardware)**

Goal: `gg flash controller` reboots the board into the ROM bootloader without touching
buttons. The button sequence stays valid forever because the bootloader is in ROM.

- [x] 4.1 Firmware, `gaggiano-controller-v1.ino` plus new `dfu_jump.cpp/.h` (written and compiled 2026-09-01; design changed from RTC backup register to a `.noinit` RAM marker checked by a `constructor(100)`, see notes log):
      - On USB `Serial`, accept a line `DFU` (and `VERSION`, replying with a build
        string so `gg detect` can show firmware version).
      - On `DFU`: set the pump to 0, close the solenoid, boiler PWM to 0, write a magic
        word (e.g. `0xDEADBEEF`) to RTC backup register 0 (`HAL_RTCEx_BKUPWrite`, after
        `HAL_PWR_EnableBkUpAccess()`), flush serial, `NVIC_SystemReset()`.
      - Early boot hook `initVariant()` (first call in `main()`, before `setup()`; USB
        and clocks are already up, see notes log): if the magic is present, clear it,
        detach USB, disable IRQs and SysTick, `HAL_RCC_DeInit()`, `HAL_DeInit()`, set MSP
        from `*(uint32_t*)0x1FFF0000`, call `*(uint32_t*)0x1FFF0004`.
        Keep this code minimal and behind a single `#define ENABLE_SERIAL_DFU 1`.
- [x] 4.2 (2026-09-01: bootloader appears in under 1 s after `DFU`; board returns to RUN after flash; plain resets do not re-enter DFU) Bench test with nothing but USB connected: `echo DFU > /dev/cu.usbmodemXXXX`
      (or via `gg`) must make `0483:df11` appear within 2 s. Then flash, then confirm the
      board comes back in RUN mode and the magic word is cleared (a plain reset must not
      re-enter DFU).
- [x] 4.3 Hook into `gg flash controller` step 2 (Phase 3.3). Keep the button prompt as
      the fallback when no RUN-mode device is present or the command times out.
- [x] 4.4 Safety review (done on the code: `DFU` is parsed only on USB `Serial`; `allOutputsOff()` zeroes pump, valve, boiler PWM and setpoints before the reset) of the firmware change: what happens if `DFU` arrives mid-brew
      (outputs are zeroed first), and confirm the screen cannot send it (it is only parsed
      on USB `Serial`, not on `screenSerial`).

**Checkpoint 4:** three consecutive `gg flash controller` runs with no button presses.
PASSED 2026-09-01. First attempt failed because `gg` wrote the `DFU` line through a
non-blocking open and closed the port before the CDC transfer happened; replaced by
`tools/serial-cmd.py`, which configures the port and keeps it open for a second.

---

## Phase 5: Repository cleanup (no hardware)

Do this only after Checkpoint 3, so every removal can be checked with `gg build all`.
One commit per bullet.

- [x] 5.1 Delete the Python venv in `gaggiano-v2/` (`bin/`, `lib/`, `include/`,
      `pyvenv.cfg`), fix `.gitignore` (`pyenv.cfg` typo), move `convertBmp.py` to `tools/`
      with a one-line usage note (needs Pillow: `python3 -m pip install --user pillow`, or
      `uv run --with pillow`).
- [x] 5.2 Unused LVGL image arrays: grep each symbol (`boiler`, `boilerRed`, `brew`,
      `brewRed`, `steam`, `steamRed`, `img_clothes`, `img_demo_widgets_avatar`,
      `img_lvgl_logo`) across `gaggiano-v2/`. Remove the `.c` files that are unreferenced;
      keep the source PNGs in `gaggiano-v2/asset-work/`. Rebuild; binary size should be
      unchanged (the linker was already discarding them).
- [x] 5.3 `archiveArdIDEFiles/`: keep `build.options.json`, `partitions.csv`, `notes`;
      delete `compile_commands.json`, `.elf`, `.map`, `.bin`, `.hex`, `build_opt.h`,
      `file_opts`. The FQBNs are now in `tools/targets.sh` and the findings doc.
- [x] 5.4 SD card content: create `sdcard/gaggia/` with `frank.bmp` and a README listing
      the files the firmware expects. Remove `frank.jpg` and `frank.rgb565` from the sketch
      folder (regenerable). Move `ESP32-8048S043-macsbug.pdf` and screenshots to `docs/`.
- [x] 5.5 Vendor pack: `git mv` the spec, schematic and user manual folders to
      `vendor/sunton-esp32-8048s043/`; `git rm -r` the rest of `4-2.3inch_ESP32-8048S043/`
      (demos with their own lvgl copy, Windows flash tool, font tools). Add a `README.md`
      there with the vendor download link. No history rewrite.
- [x] 5.6 Scratch sketches `SD_Test/`, `play_lcd/`, `p11_CrystalBall_scroll/`: delete.
      `gaggiano-v1/` to `archive/`. Root images to `docs/images/`.
- [x] 5.7 `git rm --cached` every tracked `.DS_Store`.
- [x] 5.8 Root `README.md`: short project description, hardware list, link to
      `docs/BUILD.md` and `docs/FLASH-STM32.md`, and the current `notes.txt` todo list
      folded in as "Known issues / ideas".

**Checkpoint 5:** `gg build all` still produces identical binaries to Checkpoint 2
(except 5.2 which should be identical too); `git ls-files | wc -l` drops from ~4100 to
roughly 2000 (libraries dominate).
PASSED 2026-09-01: controller 68,080 bytes (same as after Phase 4), screen 678,208 bytes.
Tracked files 4091 -> 1898. Note on the screen binary: two builds of identical source
differ only in the 64 bytes at offsets 177-241, the ESP-IDF app descriptor's ELF SHA-256.
Compare screen binaries with that region masked.

---

## Phase 6: Wrap up

- [x] 6.1 Update this plan's checkboxes and the findings doc with anything learned.
- [ ] 6.2 Open a PR `migration` to `main` (or merge locally) once Checkpoints 2, 3 and 5
      pass. Tag the last IDE-era commit on `main` as `arduino-ide-last` for reference.
- [ ] 6.3 Later, separate effort (not this branch): core upgrades (esp32 3.x, lvgl 9,
      Arduino_GFX current), 16 MB partition table, unit tests for the protocol parser.

## Open questions / notes log

- 2026-09-01 (later): decision to isolate from the Arduino IDE completely. `gg setup`
  now installs cores and toolchains into `.arduino-data/` in the repo (git-ignored)
  instead of sharing `~/Library/Arduino15`. Phase 0.4 (repointing the IDE config) is
  therefore moot. CI caches `.arduino-data/` keyed on `tools/targets.sh`.
  Verification: cores and tool versions installed into `.arduino-data/` are identical to
  the IDE's copies with one exception. The current STM32duino index only offers the
  Intel (x86_64) macOS build of xpack gcc 13.2.1-1.1; the IDE had downloaded the ARM64
  build from an earlier index (its tarball is still in `~/Library/Arduino15/staging`).
  Same compiler and newlib versions built on another host: the controller binary keeps
  the same size and identical symbol sizes but a slightly different layout (1366 bytes
  differ). The screen binary differs only by the longer core source path embedded by
  `__FILE__` in `esp32-hal-uart.c` (+16 bytes) and the resulting address shifts. Both
  builds are deterministic. Both boards were flashed from the isolated build on
  2026-09-01 (controller answered `VERSION`, screen booted). Decision: use what the index provides (reproducible on any
  machine) rather than copying the ARM64 toolchain from the IDE directory.

- 2026-09-01: Phase 4 implementation detail. The marker is two `.noinit` words
  (`dfu_jump.cpp`), set by `dfu_request_reboot()` before `NVIC_SystemReset()`. A
  `constructor(100)` (the core's `premain()` is 101) checks it before any HAL/USB init,
  clears it, disables SysTick and NVIC, remaps system memory to 0, sets MSP and jumps to
  `0x1FFF0004`. Verified in the ELF: `.init_array` lists `dfu_check_marker` first, then
  `premain`; `.noinit` at 0x200018f8 is outside `.bss`. `-Wprio-ctor-dtor` is silenced
  locally. Not yet run on hardware (4.2).
- 2026-09-01: `arduino-cli upload` is used for the actual programming step of both
  targets (it reproduces the IDE's exact esptool / stm32CubeProg.sh invocations); `gg`
  adds detection, the DFU wait loop and retries around it.
- 2026-09-01: `system_profiler SPUSBDataType -json` returns an empty list on this macOS,
  so `usb-detect.py` parses `ioreg -p IOUSB -l` instead.

- 2026-09-01: `sketch.yaml` profiles with local library directories: supported by
  arduino-cli 1.3.1 (`--dump-profile` emits `- dir: <path>` entries), so 2.5 is viable.
- 2026-09-01: `initVariant()` confirmed in the 2.9.0 core `main.cpp`: it is the first
  call in `main()`, before `setup()`. Clocks, HAL and (with `usb=CDCgen`) the USB device
  are already initialised by `premain()` at that point, so the jump code in 4.1 must
  detach USB (`USBDevice.detach()` or `HAL_PCD_DeInit`) and de-init RCC/HAL before
  jumping. Alternative if that proves fragile: a `__attribute__((constructor(101)))`
  function, which runs before `premain()`.

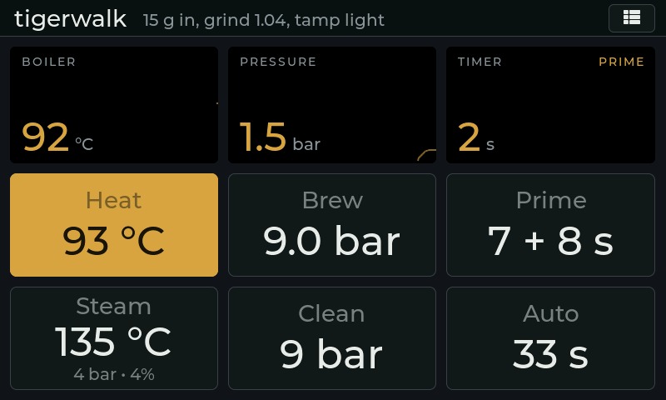
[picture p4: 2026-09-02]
docs/images/ui-prime.png

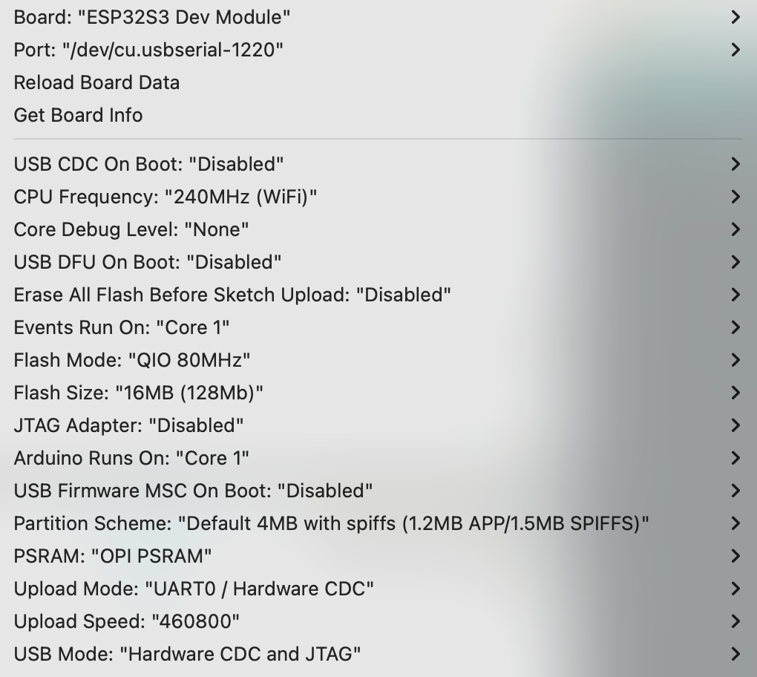
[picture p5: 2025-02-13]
docs/images/arduino-ide-esp32-settings.png

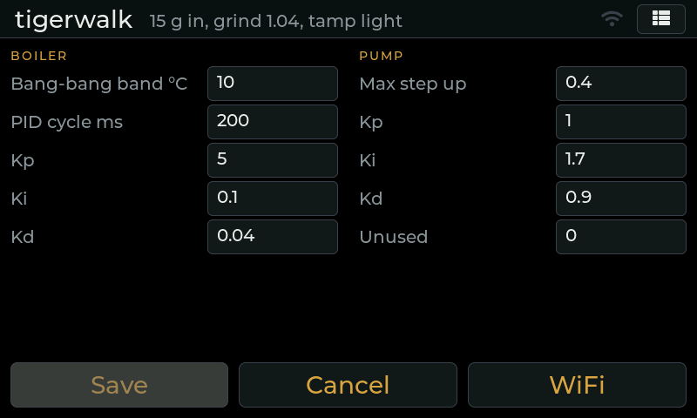
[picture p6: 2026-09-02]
docs/images/ui-advanced.png

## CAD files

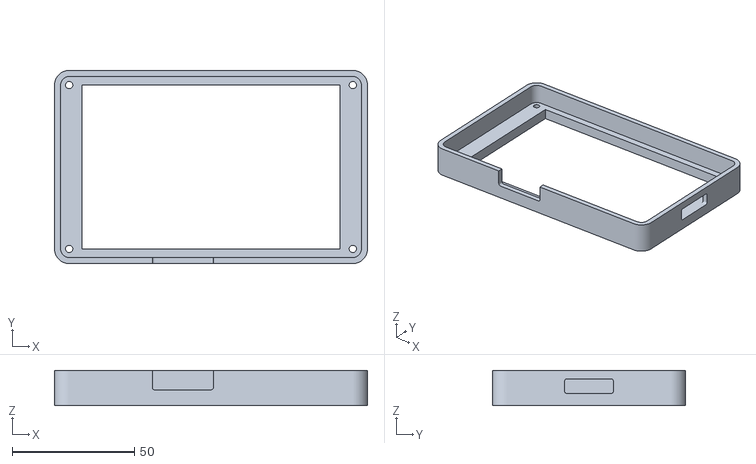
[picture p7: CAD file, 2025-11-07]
gaggiacover/v1 (failed)/GaggiaCover - Part 1.stl
128.0 x 79.0 x 14.5

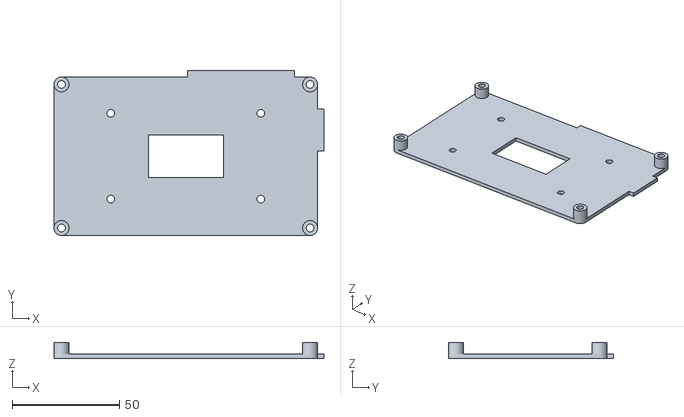
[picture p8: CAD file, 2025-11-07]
gaggiacover/v2/GaggiaCoverV2 - Part 2.stl
126.0 x 77.0 x 7.50

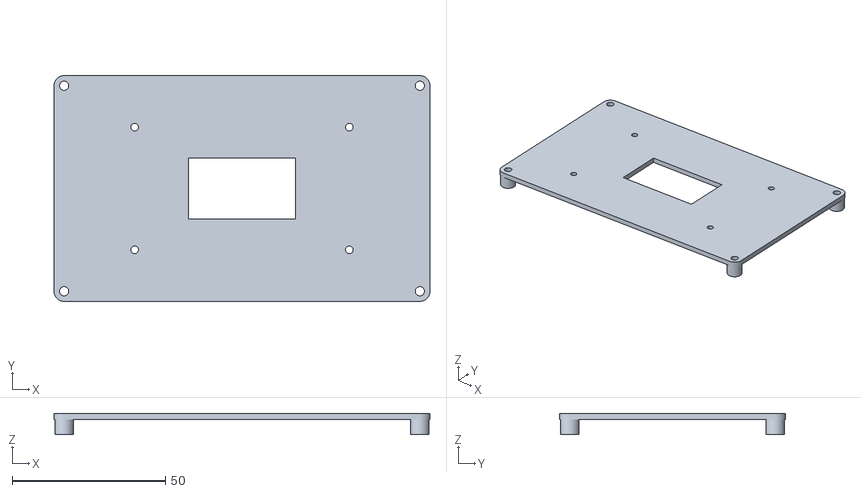
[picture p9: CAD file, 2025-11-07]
gaggiacover/v1 (failed)/GaggiaCover - Part 2.stl
122.6 x 73.6 x 7.00

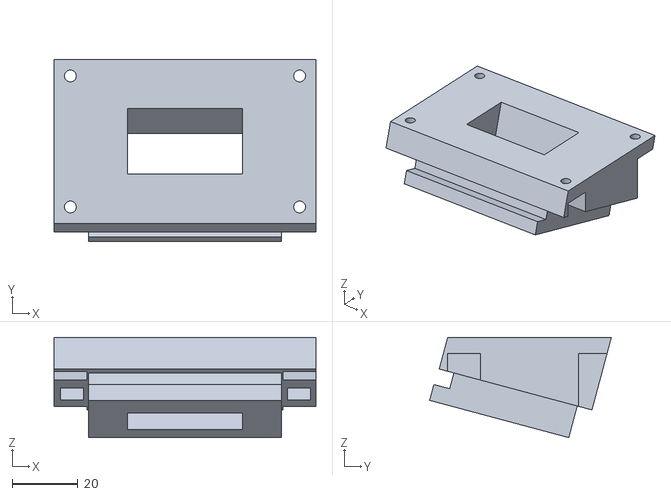
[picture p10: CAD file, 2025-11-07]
gaggiacover/v2/GaggiaCoverV2 - Part 3.stl
80.0 x 55.5 x 30.6

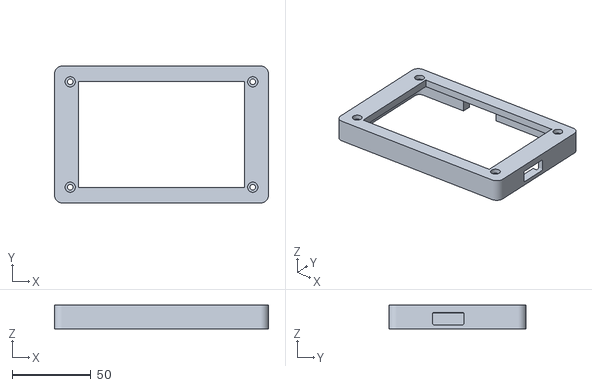
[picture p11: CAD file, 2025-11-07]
gaggiacover/v2/GaggiaCoverV2 - Part 1.stl
136.0 x 87.0 x 15.0

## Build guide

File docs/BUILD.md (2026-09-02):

# Building and flashing Gaggiano

Everything goes through `./gg`, a small bash script around `arduino-cli`. The Arduino
IDE is no longer needed. Board options, pinned core versions and USB identities live in
one place: `tools/targets.sh`.

## One-time setup (macOS)

```
brew install arduino-cli        # ./gg setup does this for you if brew is present
./gg setup
```

`setup` writes `tools/arduino-cli.yaml` (git-ignored, absolute paths), points the
sketchbook at this repo so the vendored `libraries/` folder is used, and installs the two
pinned cores with their toolchains into `.arduino-data/` inside the repo (git-ignored,
a few GB, one-time download):

| Target | Core | Version |
|---|---|---|
| controller | STMicroelectronics:stm32 | 2.9.0 |
| screen | esp32:esp32 | 3.3.11 |

Nothing outside the repo is read at build time except the compilers' own caches in
`~/Library/Caches/arduino`. The Arduino IDE and its `~/Library/Arduino15` directory are
not used at all; they can be removed. `./gg clean --all` deletes `.arduino-data/` and
the next `./gg setup` downloads it again.

Flashing the controller uses `dfu-util` from Homebrew; `setup` installs it. ST's
STM32CubeProgrammer is optional (`--via cubeprog`).

## Commands

```
./gg build all              # both targets, binaries in build/<target>/
./gg build controller       # or screen; add --clean to drop the compile cache
./gg detect                 # what is plugged in, and on which port
./gg flash screen           # build + esptool over the CH340 port
./gg flash controller       # build + DFU (see docs/FLASH-STM32.md)
./gg monitor controller     # serial monitor at 9600 (screen: 115200)
./gg clean
```

`flash` accepts `--no-build`, `--port /dev/cu.xxx`, `--timeout 120` and
`--via stlink` (controller only, needs an ST-Link on the SWD header).

## Updating the screen over WiFi

Once the screen is on the network (`docs/WEB.md`):

```
./gg flash screen --ota            # host gaggiano.local
./gg flash screen --ota 192.168.1.42
```

The build is sent as an HTTP upload to the screen's own web server (`POST /update`), so
it works whenever the Mac can reach the screen, including across an IoT network. The
panel goes dark while the flash is written (redraws would come out garbled) and comes
back with the restart; the progress is printed on the USB console. The web page has the same upload under
"Update firmware", usable from a phone. The password is `gaggiano` unless
`tools/ota-password` (git-ignored) says otherwise; the screen's own password is set on
its WiFi view ("Firmware update" password) and defaults to `gaggiano`. The USB path keeps working as before.

## Partition scheme of the screen

The screen uses the core's `app3M_fat9M_16MB` scheme: two 3 MB app slots (needed for
over-the-air updates) and a 9.9 MB FAT partition. The first flash after changing the
scheme (2026-09-02, core 3.3.11) must erase the whole chip once:

```
./gg flash screen --erase
```

Profiles and logs live on the SD card and are not affected.

## Troubleshooting the screen upload

| Symptom | Meaning |
|---|---|
| `Could not configure port: (6, 'Device not configured')` | macOS CH340 quirk on the first open after plugging in. `gg` retries three times and drops to 115200 on the last try. Plugging directly into the Mac (no hub) helps. |
| `detect` shows the screen as `usbserial-XXXX` although the WCH driver is installed | Apple's built-in CH340 driver claimed the device. Both work; if uploads keep failing, disable one driver. |
| No port at all | the board's CH340 needs a data cable; the S3's own USB connector is not used by this build. |

## Where things are

| Path | Purpose |
|---|---|
| `gaggiano-controller-v1/` | STM32 sketch |
| `gaggiano-v2/` | ESP32-S3 display sketch |
| `libraries/` | vendored Arduino libraries, including the project `lv_conf.h` for LVGL |
| `tools/targets.sh` | FQBN, core version, baud rate and USB ids per target |
| `tools/usb-detect.py` | USB enumeration helper used by `detect` and `flash` |
| `tools/serial-cmd.py` | send one line to a serial port and print the reply; `--list` shows ports, `--help` for usage |
| `tools/convertBmp.py` | PNG/BMP to raw RGB565 (needs Pillow) |
| `sdcard/` | files for the display's SD card |
| `vendor/sunton-esp32-8048s043/` | display board datasheets, schematics, manual |
| `archive/gaggiano-v1/` | first display firmware, kept for reference |
| `build/` | build output, git-ignored |
| `.github/workflows/build.yml` | CI: compiles both targets on every push |

## Changing a board option

Edit the `T_FQBN` line for the target in `tools/targets.sh`. Valid option names and
values are in the core's `boards.txt`, for example
`.arduino-data/packages/esp32/hardware/esp32/3.3.11/boards.txt`. The full menu is
also printed by `arduino-cli --config-file tools/arduino-cli.yaml board details --fqbn <fqbn>`.

## Adding a library

Drop it in `libraries/<Name>/` (the Library Manager layout: `library.properties` plus
`src/`). No registration needed; the sketchbook is this repo. Prefer copying a released
version and note the version in the commit message.

## Reproducibility notes

The CLI build was checked against the last Arduino IDE build on 2026-09-01: identical
compiler flags and include paths for both targets. Details in
`docs/2026-09-01-findings.md` and `docs/MIGRATION-PLAN.md`.

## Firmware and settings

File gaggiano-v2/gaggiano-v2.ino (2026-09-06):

// Gaggiano screen: ESP32-S3 with a 4.3" touch panel (Sunton ESP32-8048S043).
// LVGL user interface, brew profiles and logs on the SD card, and the serial
// link to the STM32 controller. See docs/ in the repository root.
//
// Modules: config.h (pins, periods), display_glue (panel, LVGL drivers, touch,
// splash), lv_buildUI (the UI), storage (SD card), sequencer (bloom/auto/brew
// phases), link (controller protocol), console (USB commands).

#include <lvgl.h>
#include <gaggia_protocol.h>
#include "config.h"
#include "gaggia_state.h"
#include "display_glue.h"
#include "lv_buildUI.h"
#include "storage.h"
#include "link.h"
#include "sequencer.h"
#include "console.h"
#include "net.h"
#include "webui.h"

GaggiaStateT state = { false, 98, 8.0, 134, 0, 0, 0.15, 2, 130, 0, 0, 0, 0, false, "", "", 0, 0, false, 0, false, false, false, false, false, false, false, false, 0, 0 };
AdvancedSettingsT advancedSettings = { false, false, 3, 1000, 10, 0.2, 0.1, 1, 100, 1, 0.1, 9 };
bool isControllerLoggingOn = true;  // CSV rows to the SD card (console: SDLOG OFF to stop)

HardwareSerial controllerSerial(2);

void setup() {
  consoleSetup();
  controllerSerial.setRxBufferSize(CONTROLLER_RX_BUFFER);
  controllerSerial.begin(CONTROLLER_BAUD, SERIAL_8N1, CONTROLLER_RX_PIN, CONTROLLER_TX_PIN);
  linkSetup(&controllerSerial, &state, &advancedSettings);
  linkSetCommand(GP_MODE_OFF, 0, 0, 0);  // initial command: everything off; starts the 1 s heartbeat
  netBegin();
  webBegin();

  if (!displaySetup()) return;  // no display: keep the link and console alive anyway

  initConfFile(&state, &advancedSettings);
  displaySplash();

  instantiateUI(&state, &advancedSettings, writeConfigFile, listProfiles, getCurrentProfile,
                writeCurrentProfile, setupAndReadConfigFile, renameProfile, deleteProfile, duplicateProfile);
  setupAndReadConfigFile();
  storageStartSession();
  logController("#,screen boot " SCREEN_FIRMWARE_VERSION);
  Serial.println("Setup done");
}

static uint32_t lastUiRefresh = 0;

void loop() {
  uint32_t now = millis();
  linkPoll(now);
  netPoll(now);
  webPoll(now);
  storageSessionTick();
  if (state.cleanLogs) {
    state.cleanLogs = false;
    storageStartSession();
    logController("#,logs cleared from the screen");
  }
  consolePoll(now);
  if (now - lastUiRefresh >= UI_REFRESH_MS) {
    lastUiRefresh = now;
    updateUI();
  }
  lv_timer_handler();  // let the GUI do its work

  SeqCommand c;
  if (sequencerStep(&state, now, &c)) linkSetCommand(c.mode, c.tempSet, c.pressSet, c.pumpPct);
  if (advancedSettings.sendToController) {
    linkSendTune();
    advancedSettings.sendToController = false;
  }
  delay(5);
}

// Images: converted with the LVGL image converter v8, https://lvgl.io/tools/imageconverter

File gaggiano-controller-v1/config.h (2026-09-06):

// Pins, periods and limits for the STM32F411 controller. Single place to edit.
#pragma once

#define FIRMWARE_VERSION "controller-2026-09-06-r1"  // sent in HELLO: no commas, max 31 chars

#define LOOP_PERIOD_MS 10

// --- sensors
#define PRESSURE_READ_PERIOD_MS 10
#define PRESSURE_RETRY_PERIOD_MS 250   // while I2C reads fail: each attempt costs an I2C timeout (build_opt.h)
#define PRESSURE_STALE_MS 500          // no good reading for this long: the pump stays off
#define I2C_RECOVER_AFTER_FAULTS 8     // consecutive failed reads before the bus is clocked free and the ADC re-initialised
#define TEMP_READ_PERIOD_MS 250
#define I2C_SDA_PIN PB7
#define I2C_SCL_PIN PB6
#define ADS1115_ADDRESS 0x48
#define MAX6675_CS PA6
#define MAX6675_SO PB4
#define MAX6675_SCK PA5

// --- outputs
#define VALVE_PIN PC13
#define PUMP_ZC_PIN PA15
#define PUMP_DIMMER_PIN PB3
#define PUMP_ZC_MODE RISING
#define PUMP_RANGE 127
#define PUMP_MAX 255
#define STEAM_PUMP_MAX_PERCENT 50    // cap on the pump while steaming (solenoid closed)
#define STEAM_OPEN_BB_RANGE 3.0      // steaming with the wand open: heater flat out below setpoint minus this (the normal band is boiler_bb_range)
#define STEAM_ASSIST_BLANK_S 0.3     // pressure ignored for this long after a shot: the pump's own pulses raise it
#define BOILER_RELAY_PIN PB5
#define BOILER_RELAY_FREQ_HZ 30

// --- boiler PID
#define BOILER_OUTPUT_MIN 0
#define BOILER_OUTPUT_MAX 100
#define BOILER_KP 10
#define BOILER_KI .2
#define BOILER_KD .1
#define BOILER_ELEMENT_W 1400      // heating element, for the brew feed-forward
#define BREW_INLET_C 20            // reservoir water temperature assumed by the feed-forward
#define BREW_BOOST_MAX_PCT 40      // cap on the feed-forward; the PID does the rest

// --- screen link (USART2)
#define SCREEN_RX_PIN PA3
#define SCREEN_TX_PIN PA2
#define SCREEN_BAUD 115200
#define STATUS_SEND_PERIOD_MS 200  // 200 is a decent value for screen updates; last known working value was 500
#define LINK_TIMEOUT_MS 3000       // no valid CMD for this long: pump off, valve closed, boiler keeps its setpoint
#define LINE_MAX 128               // console line buffer

// --- watchdog: reset if the loop stalls (outputs go to reset state: all off)
#define WATCHDOG_TIMEOUT_US 4000000

// --- USB console
#define CONSOLE_BAUD 9600

// --- operating modes (values are part of the wire protocol, see GaggiaProtocol GpMode)
#define OPERATING_MODE_OFF 0
#define OPERATING_MODE_BREW 1
#define OPERATING_MODE_STEAM 2
#define OPERATING_MODE_CLEAN 3

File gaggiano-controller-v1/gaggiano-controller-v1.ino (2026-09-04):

// Gaggiano controller: STM32F411 "Black Pill". Reads boiler temperature and
// pressure, drives the boiler SSR, the pump and the solenoid valve, and talks
// to the touch screen over USART2. See docs/ in the repository root.
//
// Modules: config.h (pins, periods), sensors, outputs, control, link (screen
// serial protocol), console (USB commands), dfu_jump (reboot to bootloader).

#include "config.h"
#include "sensors.h"
#include "outputs.h"
#include "control.h"
#include "link.h"
#include "console.h"
#include <IWatchdog.h>

uint32_t loopCounter = 0;
uint32_t maxLoopMs = 0;             // since boot, for the console
static uint32_t statMaxLoopMs = 0;  // since the last STAT, goes on the wire

bool resetByWatchdog = false;

void setup() {
  resetByWatchdog = IWatchdog.isReset();
  if (resetByWatchdog) IWatchdog.clearReset();
  consoleSetup();
  if (resetByWatchdog) Serial.println("reset by watchdog");
  linkSetup();
  sensorsSetup();
  outputsSetup();
  controlSetup();
  IWatchdog.begin(WATCHDOG_TIMEOUT_US);
}

void loop() {
  uint32_t loopStart = millis();

  bool tempUpdated = readTemperature(loopStart);
  bool pressureUpdated = readPressure(loopStart);

  pollScreenSerial();
  checkLinkTimeout(loopStart);
  readUsbCommand();

  if (tempUpdated) updateBoiler();
  if (pressureUpdated) updatePump2();  // pump and solenoid (coupled)

  if (sendStatus(loopStart, loopCounter, statMaxLoopMs)) statMaxLoopMs = 0;

  loopCounter++;
  uint32_t elapsed = millis() - loopStart;
  if (elapsed > maxLoopMs) maxLoopMs = elapsed;
  if (elapsed > statMaxLoopMs) statMaxLoopMs = elapsed;
  // Only sleep for the remainder of the period (an unsigned subtraction here
  // used to turn any slow iteration into a ~49 day delay).
  if (elapsed < LOOP_PERIOD_MS) delay(LOOP_PERIOD_MS - elapsed);
  IWatchdog.reload();
}

// Hardware notes kept from the original single-file sketch:
// - USB CDC must be enabled in the build (usb=CDCgen) for Serial to exist.
//   https://www.stm32duino.com/viewtopic.php?t=1353
// - The relay on the solenoid can prevent DFU enumeration; turning brew on
//   before entering DFU helps.
// - PB5 PWM for the boiler relay follows the HardwareTimer All-in-one_setPWM example.
// - The valve relay had to be wired normally closed.
// - PSM (pump) library from https://github.com/banoz/PSM.Library.git, copied in.

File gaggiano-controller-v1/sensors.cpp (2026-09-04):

#include "sensors.h"
#include "config.h"
#include <Wire.h>
#include <ADS1X15.h>
#include <max6675.h>
#include <SimpleKalmanFilter.h>

double temperature_read = 0;
double temperature_smoothed = 0;
double pressure_read = 0;
double pressure_smoothed = 0;
uint32_t temperatureFaults = 0;
uint32_t pressureFaults = 0;
uint32_t i2cRecoveries = 0;
bool pressureStale = true;  // no good reading yet

static ADS1115 ADS;
static MAX6675 thermocouple(MAX6675_SCK, MAX6675_CS, MAX6675_SO);
static SimpleKalmanFilter smoothPressure(0.6f, 0.6f, 0.1f);
static SimpleKalmanFilter smoothTemperature(0.25f, 0.25f, 0.01f);

static uint32_t last_temp_read_time = 0;
static uint32_t last_pressure_read_time = 0;
static uint32_t last_good_pressure_time = 0;
static uint32_t pressure_fault_streak = 0;  // consecutive failed reads

// Configures the ADC when it answers; when it does not (not wired, bus stuck) the
// next failed reads bring us back here through the recovery.
static void adsInit() {
  if (!ADS.begin()) {
    ADS.getError();
    return;
  }
  ADS.setGain(0);      // 6.144 volt
  ADS.setDataRate(7);  // fast
  ADS.setMode(0);      // continuous mode
  ADS.readADC(0);      // first read to trigger
  ADS.getError();      // clear whatever the init left behind
}

void sensorsSetup() {
  Wire.setSDA(I2C_SDA_PIN);  // should not be necessary.. default value
  Wire.setSCL(I2C_SCL_PIN);  // should not be necessary.. default value
  ADS = ADS1115(ADS1115_ADDRESS, &Wire);
  Wire.begin();
  adsInit();
}

// A slave interrupted mid-transfer (a glitch on the bus while it was driving SDA)
// keeps SDA low and every transaction after that times out; seen 2026-09-04, the
// ADS1115 stopped answering 11 s after a clean cycle and never came back. Clocking
// SCL by hand lets the slave finish its byte, a STOP releases the bus, then the
// peripheral and the ADC are set up again.
static void i2cBusRecover() {
  Wire.end();
  pinMode(I2C_SDA_PIN, INPUT_PULLUP);
  pinMode(I2C_SCL_PIN, OUTPUT_OPEN_DRAIN);
  for (int i = 0; i < 9; i++) {
    digitalWrite(I2C_SCL_PIN, LOW);
    delayMicroseconds(5);
    digitalWrite(I2C_SCL_PIN, HIGH);
    delayMicroseconds(5);
  }
  pinMode(I2C_SDA_PIN, OUTPUT_OPEN_DRAIN);  // STOP: SDA low then high while SCL is high
  digitalWrite(I2C_SDA_PIN, LOW);
  delayMicroseconds(5);
  digitalWrite(I2C_SCL_PIN, HIGH);
  delayMicroseconds(5);
  digitalWrite(I2C_SDA_PIN, HIGH);
  delayMicroseconds(5);
  Wire.begin();
  adsInit();
  i2cRecoveries++;
}

static float toBar(int16_t raw) {
  // voltageZero = 0.5V --> 2666.7 (ADS 15 bit), voltageMax = 4.5V --> 24000
  // pressure gauge range 0-1.2MPa - 0-12 bar, 1 bar = 1777.8 counts
  return (raw - 2666) / 1777.8f;
}

// Returns true whenever an attempt was made, so the control law runs on a failed
// read too and can see `pressureStale`. While the bus is failing the attempts are
// spaced out (each one costs an I2C timeout) and the bus is recovered every
// I2C_RECOVER_AFTER_FAULTS attempts. The last good value is kept; the library
// would otherwise hand back 0, which reads as -1.5 bar.
bool readPressure(uint32_t now) {
  uint32_t period = pressure_fault_streak > 0 ? PRESSURE_RETRY_PERIOD_MS : PRESSURE_READ_PERIOD_MS;
  if ((now - last_pressure_read_time) <= period) return false;
  last_pressure_read_time = now;
  int16_t raw = ADS.getValue();
  if (ADS.getError() != ADS1X15_OK) {
    pressureFaults++;
    pressure_fault_streak++;
    pressureStale = (now - last_good_pressure_time) >= PRESSURE_STALE_MS;
    if (pressure_fault_streak % I2C_RECOVER_AFTER_FAULTS == 0) i2cBusRecover();
    return true;
  }
  pressure_fault_streak = 0;
  last_good_pressure_time = now;
  pressureStale = false;
  pressure_read = toBar(raw);
  pressure_smoothed = smoothPressure.updateEstimate(pressure_read);
  return true;
}

bool readTemperature(uint32_t now) {
  if ((now - last_temp_read_time) > TEMP_READ_PERIOD_MS) {
    double newReading = thermocouple.readCelsius();
    // The machine never runs near freezing or above 200 C; anything outside is a
    // sensor fault (the MAX6675 returns 0 or NaN with an open thermocouple). Keep
    // the last good value so the PID does not react to it.
    if (newReading > 1 && newReading < 200) {
      temperature_read = newReading;
      temperature_smoothed = smoothTemperature.updateEstimate(temperature_read);
    } else {
      temperatureFaults++;
    }
    last_temp_read_time = now;
    return true;
  }
  return false;
}

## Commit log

2025-02-15 added buttons to settings
2025-02-17 buttons ready. time to connect and arduino
2025-02-22 screen sends commands. controller doesn't parse yet
    [gaggiano-v2.ino]
2025-02-23 comms work. beware of ports in arduino IDE (disappear, full restart needed), and perceived lag on screen because many messages queued and only processing one per loop. coordinating loop frequency sho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
    [gaggiano-controller-v1.ino, gaggiano-v2.ino]
2025-03-01 attempt at ADS1115 failed. now STM is unworkable. moving to nano clone
    [gaggiano-controller-v1.ino]
2025-03-09 pressure read! next is PID for pressure, then solenoid
2025-03-10 solenoid connected. now onto pump
2025-03-10 fully wired and functional. UI might still have bugs, especially new advanced screen
    [gaggiano-controller-v1.ino, gaggiano-v2.ino]
2025-03-19 functional! tested with coffee ok. Pressure reading is completely off (all over the place) but obviously the pump is being controlled ok. sometimes 0 reading on temp, would be nice to ignore. Not sur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
    [gaggiano-controller-v1.ino, gaggiano-v2.ino]
2025-03-19 fix sync start (screen wait for controller to send saved advanced settings) increase frequency of controller updates, fix sync of messages to avoid truncated messages when uart buffer overflows
    [gaggiano-controller-v1.ino, gaggiano-v2.ino]
2025-03-22 works, temp is better, pressure is ok, but maybe still brutal. steam with pump is not great.
2025-03-22 pressure improvements, most settings saved
2025-03-23 blooming and timer implemented
2025-03-28 fix temp control during brewing
    [gaggiano-v2.ino]
2025-03-28 all files needed for project
    [partitions.csv, pyvenv.cfg]
2025-04-08 fixed the missing zero, and prevent brew and steam pressed at the same time, for simplicity
    [gaggiano-v2.ino]
2025-05-18 fixed bug in setting changed. Improve first image loading. Further improvement: save file with pre-computed bmp if time gain worth it
    [BmpClass.h, BmpClassRowByRow.h, gaggiano-v2.ino]
2025-11-07 3D models for screen cover
    [GaggiaCover - Part 1.stl, GaggiaCover - Part 2.stl, GaggiaCoverV2 - Part 1.stl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]
2026-09-01 Migration (#1)
    * docs
    * migration: repo-local arduino-cli config and build/ ignore (plan 0.2, 0.3)
    * migration: Phase 1 build reproduction verified, sizes recorded
    * migration: gg build script, USB detection, docs and CI (plan 2.1-2.4)
    * migration: serial-triggered DFU entry in controller firmware, plan progress (3.x, 4.1, 4.3, 4.4)
    * migration: screen flash verified on hardware; retry with baud fallback (plan 3.2)
    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
    [pyvenv.cfg]
2026-09-02 Refactoring (#2)
    * refactor: plan with bug inventory, protocol v2 design and decisions
    * refactor: host test harness (gg test), bench checklist, baseline (plan R0.1-R0.3)
    * refactor: controller STATUS/LOG console commands, screen HEAP report (plan R0.4)
    * refactor: fix loop delay underflow on slow iterations (B3, plan R1.1)
    * refactor: temperature filter used || instead of &&; count sensor faults (B2, plan R1.2)
    * refactor: non-blocking line reader and in-place parser for the screen link; unknown messages ignored (B1, B4, B12, plan R1.3)
    Adds RX <line> console command to inject a line for bench tests. Drops the dead
    updatePump() and the leaking mySubString/myIndexOF helpers.
    * refactor: UART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
    [config.h, console.cpp, display_glue.cpp]
2026-09-02 U iv2 (#3)
    * ui: plan for the main screen redesign (simulator, theme, header menu, tiles with curves, buttons)
    * ui: screen simulator on the Mac (SDL2), gg sim, first screenshot of the current UI (plan U1)
    * ui: theme module (palette, fonts, styles by role) applied to the existing layout; fonts 14/20/28/48 (plan U2)
    * ui: main screen redesign: header with menu, reading tiles with curves, button grid, notes in the header (plan U3.1-U3.6)
    * ui: larger header and button type, black readouts, menu list hangs from the button's right edge, menu scene in the simulator
    * ui: menu list opens leftwards from the icon so it stays on screen
    * ui: black ground, muted button names, steam temperature big wi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
    [console.cpp, history.h, link.cpp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]
2026-09-02 Advanced stuff (#4)
    * wifi: plan (core upgrade, WiFi setup view, NTP, web page, OTA, optional scale); UI plan closed
    * core: Arduino_GFX 1.2.8 -> 1.6.7 (required by the esp32 3.x core) (plan W1.2)
    * core: screen on esp32 core 3.3.11 with the 16 MB partition scheme; display glue on the new RGB panel classes; gg flash --erase (plan W1.1, W1.3, W1.4)
    * wifi: network module (STA, NVS credentials, NTP with time zone), WiFi view from Advanced, header clock and symbol, timestamped log, STATUS fields; simulator stub (plan W2.1-W2.4, W3.1-W3.3)
    * wifi: web page (status, live chart, log download), HTTP server with JSON endpoints, mDNS gaggiano.local; CSV log rows at a sensible rate; docs/WEB.md (plan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
2026-09-04 fix IC2 stall
2026-09-05 fix: initialize controller variables
    [config.h, console.cpp, outputs.cpp]
2026-09-06 improved heat PID
2026-09-06 chunk web calls for screen stability
    [config.h, webui.cpp]
